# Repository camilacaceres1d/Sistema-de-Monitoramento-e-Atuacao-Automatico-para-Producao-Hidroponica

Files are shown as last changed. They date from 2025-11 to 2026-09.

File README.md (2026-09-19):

# Sistema de Monitoramento e Atuação Automático para Produção Hidropônica

Monitoramento e automação de cultivo hidropônico NFT com módulos ESP32, broker MQTT e aplicação web em Phoenix LiveView.

## Visão geral

Na técnica NFT, uma lâmina fina de solução nutritiva circula continuamente pelas raízes, e o cultivo depende de variáveis que mudam ao longo do dia: pH, condutividade elétrica, temperatura da solução, temperatura e umidade do ar, vazão e fotoperíodo. Em pequena escala, o acompanhamento é feito por medições manuais esporádicas, com bomba e iluminação em timer e sem registro histórico.

Este sistema mede essas variáveis a cada 15 segundos, grava a série histórica em banco, exibe as leituras em tempo real na web e aciona bomba e lâmpada por cronogramas configuráveis.

Custo aproximado: R$ 195,06 por módulo de reservatório e R$ 98,57 por bancada, cerca de R$ 293 para um sistema com um reservatório e uma bancada.

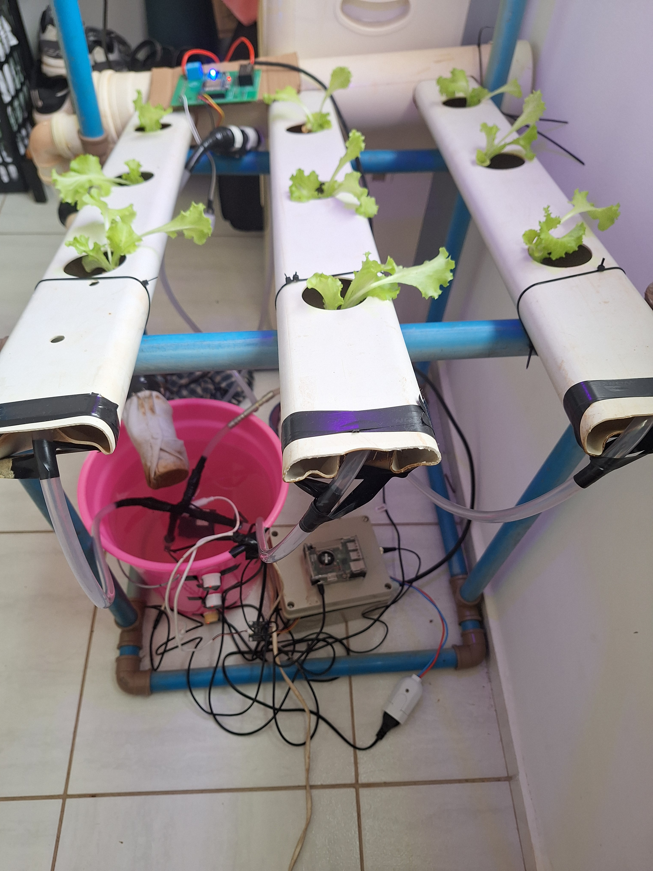
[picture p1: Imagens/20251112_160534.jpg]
Estufa hidropônica montada: três canais NFT, reservatório com as sondas de pH, EC, temperatura e nível, e o módulo de bancada fixado na estrutura


_Protótipo em operação: canais NFT em PVC, reservatório com a bomba e as sondas, módulo ESP32 da bancada no alto e caixa de passagem com o relé._

## Arquitetura

Três níveis, ligados por MQTT:

```mermaid
flowchart TB
    subgraph controle["Controle geral"]
        broker["Broker MQTT<br/>Eclipse Mosquitto (MQTT v5)<br/>Docker · Raspberry Pi 3B+"]
        subgraph app["Aplicação web (nó BEAM único)"]
            mqtt["MqttClient<br/>GenServer :emqtt"]
            logica["Sensors · Devices · Greenhouse<br/>Oban: IrrigationWorker, LightWorker"]
            lv["LiveViews<br/>Dashboard e Device"]
            db[("PostgreSQL")]
            mqtt <--> logica
            logica <--> db
            logica <--> lv
        end
        broker <--> mqtt
    end

    subgraph estufa["Estufa hidropônica"]
        subgraph res["Controle do reservatório"]
            esp1["ESP32"]
            s1["pH · TDS/EC · DS18B20<br/>3x nível XKC-Y25-V"]
            a1["Bomba submersa 600 L/h<br/>via relé"]
            s1 --> esp1 --> a1
        end
        subgraph banc["Controle da bancada"]
            esp2["ESP32"]
            s2["DHT22 · fluxo YF-S201"]
            a2["Lâmpada LED E27<br/>espectro completo via relé"]
            s2 --> esp2 --> a2
        end
    end

    esp1 -- "greenhouse/&lt;mac&gt;/sensors" --> broker
    broker -- "greenhouse/&lt;mac&gt;/commands" --> esp1
    esp2 -- "bench/&lt;mac&gt;/sensors" --> broker
    broker -- "bench/&lt;mac&gt;/commands" --> esp2
```

O broker é o único ponto de encontro entre firmware e servidor: os ESP32 não conhecem o endereço da aplicação nem ela o deles, ambos falam com `hidroponia.local:1883`.

Cliente MQTT, regras de negócio, jobs agendados e processos LiveView rodam no mesmo nó BEAM. Uma leitura que chega pelo `MqttClient` é gravada pelo contexto `Sensors` e propagada por `Phoenix.PubSub` direto para os LiveViews conectados, sem API REST intermediária.

Um detalhe do esquema de tópicos: bancadas não carregam o identificador da estufa. A vinculação entre bancada e estufa fica no banco (`devices.greenhouse_id`, editável pela interface), então mover um módulo de bancada para outra estufa não exige recompilar firmware.

## Hardware

**Módulo do reservatório** (diagrama: `Imagens/DiagramaReservatorioAnotado.png`)

| Componente | Função |
| --- | --- |
| ESP32 (MH-ET Live MiniKit) | Leitura dos sensores, publicação MQTT, acionamento do relé |
| Sensor de pH PH-4502C | pH da solução nutritiva |
| TDS Meter V1.0 | Condutividade elétrica da solução, em µS/cm |
| DS18B20 | Temperatura da solução, usada na compensação de pH e EC |
| 3x XKC-Y25-V | Nível capacitivo sem contato, sem furar o reservatório |
| Módulo relé | Chaveamento da bomba |
| Bomba submersa 600 L/h | Circulação da solução pelos canais NFT |
| Fonte Hi-Link 5 V | Alimentação a partir da rede |

Total do módulo: **R$ 195,06**

**Módulo da bancada** (diagrama: `Imagens/DiagramaBancadaAnotado.png`)

| Componente | Função |
| --- | --- |
| ESP32 (MH-ET Live MiniKit) | Leitura dos sensores, publicação MQTT, acionamento do relé |
| DHT22 | Temperatura e umidade do ar |
| YF-S201 | Vazão na bancada, por contagem de pulsos em interrupção |
| Módulo relé | Chaveamento da lâmpada |
| Lâmpada LED E27 de espectro completo | Iluminação suplementar |
| Fonte Hi-Link 5 V | Alimentação a partir da rede |

Total do módulo: **R$ 98,57**

Pinos e constantes de calibração ficam no `include/config.hpp` de cada firmware. Esquemas em Fritzing: `DiagramaBancada.fzz` e `Imagens/DiagramaReservatorio.fzz`.

## Stack

**Firmware:** C++ sobre o framework Arduino, compilado com PlatformIO para a board `mhetesp32minikit`, com PubSubClient, ArduinoJson, DallasTemperature (reservatório) e DHT sensor library (bancada).

**Aplicação:** Elixir 1.15 com Phoenix 1.8, LiveView 1.1 e Bandit; PostgreSQL via Ecto, cronogramas no Oban, gráficos em ECharts, estilo em Tailwind e `emqtt` 1.14.4 como cliente MQTT (v5).

**Infraestrutura:** Eclipse Mosquitto e PostgreSQL 15 em Docker Compose, num Raspberry Pi 3B+. O broker escuta MQTT na 1883 e WebSockets na 9001.

## Estrutura do repositório

```
.
├── SistemaReservatorio/   firmware do reservatório: src/, include/, platformio.ini, Makefile
├── SistemaBancada/        firmware da bancada, mesma organização
├── sistema_controle/      aplicação Phoenix: lib/, assets/, priv/, mosquitto/, docker-compose.yml
└── Imagens/               diagramas, esquemas Fritzing e fotos do protótipo
```

## Como executar

### Pré-requisitos

- Elixir 1.15+ e Erlang/OTP compatível
- Docker e Docker Compose
- PlatformIO Core (`pio`) para os firmwares
- Um host acessível como `hidroponia.local` na rede local, onde roda o broker

### Broker MQTT e banco

Os dois sobem pelo Compose em `sistema_controle/`:

```bash
cd sistema_controle
docker compose up -d
```

O `mosquitto.conf` usa `allow_anonymous false` e exige `/mosquitto/config/password.txt`, que não é versionado. Crie o arquivo com o usuário do firmware e do servidor:

```bash
docker compose exec mosquitto mosquitto_passwd -c /mosquitto/config/password.txt hidroponia
docker compose restart mosquitto
```

O PostgreSQL sobe com banco `hidroponia_db`, usuário `hidroponia_user` e senha `123456`, iguais aos de `config/dev.exs`. Para trocar, defina `POSTGRES_DB`, `POSTGRES_USER` e `POSTGRES_PASSWORD` antes do `up` e ajuste o `dev.exs`.

### Aplicação web

```bash
cd sistema_controle
mix setup        # deps.get, ecto.create, ecto.migrate, seeds, assets.setup, assets.build
mix phx.server   # ou: iex -S mix phx.server
```

A interface fica em http://localhost:4000. Em desenvolvimento o endpoint escuta só em `127.0.0.1`; para acessar de outra máquina, troque `ip: {127, 0, 0, 1}` por `ip: {0, 0, 0, 0}` em `config/dev.exs`. O alias `mix precommit` compila com `--warnings-as-errors`, formata e roda os testes.

### Firmwares

Cada módulo é um projeto PlatformIO independente. Ajuste `include/config.hpp` com SSID, senha do Wi-Fi e credenciais do broker; os valores versionados são os do ambiente de testes. O endereço do broker também está em `sistema_controle/lib/sistema_controle/mqtt_client.ex` e precisa bater nos três arquivos.

```bash
cd SistemaReservatorio        # ou SistemaBancada
make upload ENV=mhetesp32minikit
make monitor                  # serial a 115200 baud
```

Em PlatformIO puro:

```bash
pio run -t upload --environment mhetesp32minikit
pio device monitor -b 115200
```

`make erase ENV=mhetesp32minikit` apaga a flash; `make compiledb ENV=mhetesp32minikit` regenera o `compile_commands.json` do clangd.

A calibração do pH usa a reta de `PH_CALIBRATION_A` e `PH_CALIBRATION_B`, em `config.hpp`. A função `calibrate_ph()` imprime ADC e tensão médios para levantar os dois pontos com soluções tampão.

## Protocolo MQTT

O identificador no tópico é o MAC retornado por `WiFi.macAddress()`, no formato `AA:BB:CC:DD:EE:FF`.

| Tópico | Sentido | Conteúdo |
| --- | --- | --- |
| `greenhouse/<mac>/sensors`  | ESP32 → servidor | Leituras do reservatório, a cada 15 s |
| `greenhouse/<mac>/commands` | Servidor → ESP32 | Acionamento da bomba |
| `bench/<mac>/sensors` | ESP32 → servidor | Leituras da bancada, a cada 15 s |
| `bench/<mac>/commands` | Servidor → ESP32 | Acionamento da lâmpada |

O servidor assina `greenhouse/+/sensors` e `bench/+/sensors` com QoS 0; cada firmware assina só o próprio tópico de comandos.

Leitura do reservatório, publicada em `greenhouse/AA:BB:CC:DD:EE:FF/sensors`:

```json
{
  "ph": 6.12,
  "ec": 1184.37,
  "temp": 23.68,
  "levels": { "level0": true, "level1": true, "level2": false },
  "pump": true,
  "ts": 1358230
}
```

`ec` é a condutividade em µS/cm. O firmware aplica a curva do TDS Meter (`133.42·V³ − 255.86·V² + 857.39·V`) sobre a tensão já compensada em temperatura, sem multiplicar pelo fator TDS de 0,5, então o valor publicado é condutividade e não sólidos dissolvidos em ppm. Os três níveis são booleanos de presença de água em alturas diferentes do reservatório. `ts` é o `millis()` da placa, não um horário absoluto: o registro temporal é o `inserted_at` gravado pelo servidor.

Leitura da bancada, publicada em `bench/AA:BB:CC:DD:EE:FF/sensors`:

```json
{
  "flow": 1.87,
  "air_temp": 26.4,
  "air_humidity": 62.1,
  "light": false,
  "ts": 1358430
}
```

Comandos, publicados pelo servidor:

```json
{ "atuador": "bomba", "valor": true }
```

```json
{ "atuador": "luz", "valor": true }
```

O firmware do reservatório só reage a `"atuador": "bomba"`, e o da bancada só a `"atuador": "luz"`. Outros valores são registrados no serial e ignorados.

Cadastro automático: ao receber mensagem de um MAC desconhecido, `Devices.create_or_update_device/2` cria o registro, nomeia como "Estufa N" ou "Bancada N" e, para estufas, cria a configuração padrão. Ligar um módulo novo na rede basta para ele aparecer na interface.

## Resultados

O sistema foi validado em um cultivo real de alface crespa.

| 05/11/2025 | 12/11/2025 |
| --- | --- |
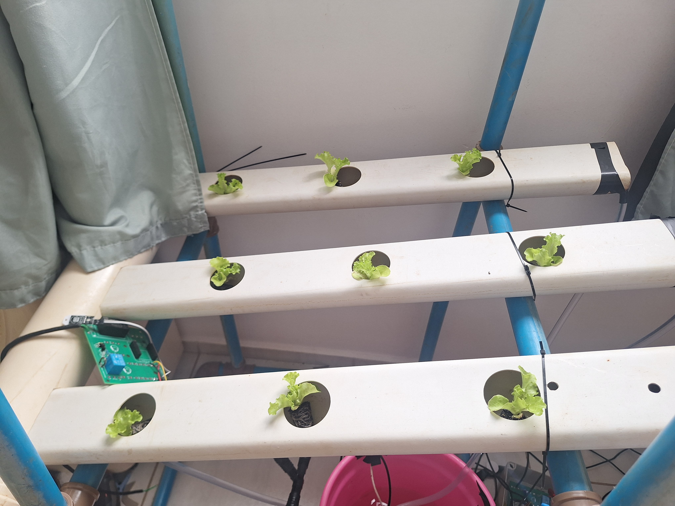
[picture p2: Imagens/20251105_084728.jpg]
Mudas de alface recém-transplantadas nos canais NFT
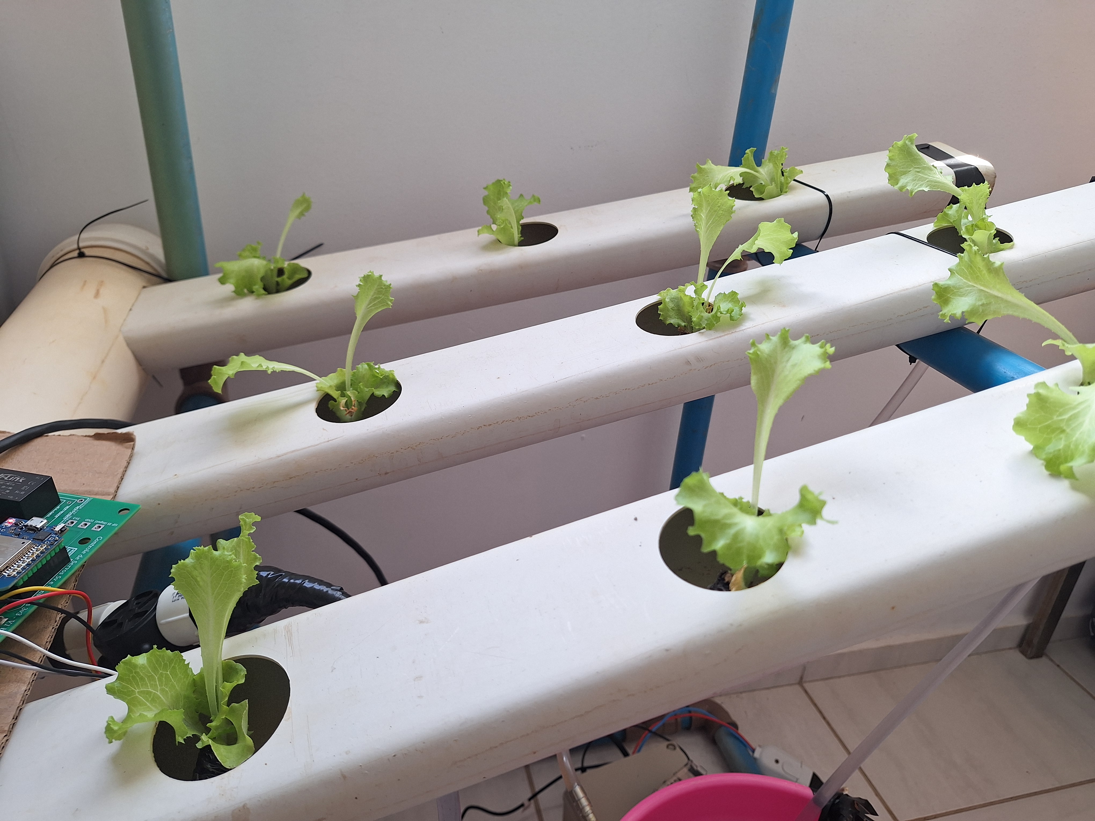
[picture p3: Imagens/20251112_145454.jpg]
Alfaces desenvolvidas nos mesmos canais uma semana depois
|  |  |
| Mudas recém-transplantadas, no início do monitoramento | As mesmas posições após uma semana de operação contínua |

Durante o ciclo, foram verificados:

- Telemetria dos dois módulos a cada 15 segundos, com série histórica persistida e visualização em tempo real
- Cadastro automático de módulos na primeira publicação
- Troca de uma bancada entre estufas pela interface, sem regravar firmware
- Cronogramas de bomba e lâmpada por janela de horário, dias da semana e ciclos liga/desliga em minutos
- Acionamento manual pela interface, com retorno do estado na leitura seguinte

**Limitação conhecida do sensor de pH.** O sensor de pH e o sensor de EC compartilham a mesma solução e o mesmo referencial de terra, e a excitação do eletrodo de EC injeta corrente na água que desloca a leitura do eletrodo de pH. A mitigação adotada é digital: `read_ph()` coleta 50 amostras, ordena o vetor e faz a média apenas do quartil central, descartando os extremos; a mesma filtragem é aplicada ao EC com 30 amostras, e ambas as leituras recebem compensação de temperatura a partir do DS18B20. A filtragem reduz o ruído, mas não elimina o desvio: a interferência eletroquímica permanece e a leitura de pH deve ser tratada como indicativa, com conferência periódica por medição manual. A solução definitiva passa por isolamento galvânico entre as sondas ou por alternar a excitação dos dois sensores no tempo.

## Publicação

Trabalho de conclusão de curso em Ciência da Computação, Faculdade de Computação (FACOM) da Universidade Federal de Mato Grosso do Sul (UFMS), 2025. Publicado nos anais do VII Congresso Brasileiro Interdisciplinar em Ciência e Tecnologia (COBICET), 2026.

> CÁCERES, Camila Cardoso; JUNQUEIRA, Luiz Gustavo S. S. **Sistema automático de monitoramento e atuação para produção hidropônica**. In: CONGRESSO BRASILEIRO INTERDISCIPLINAR EM CIÊNCIA E TECNOLOGIA, 7., 2026. Anais [...]. Even3, 2026.

https://www.even3.com.br/anais/cobicet2026-628540/1606975-sistema-automatico-de-monitoramento-e-atuacao-para--producao-hidroponica

## Autores

- Camila Cardoso Cáceres
- Luiz Gustavo S. S. Junqueira

Orientação: Profa. Hana Karina Salles Rubinsztejn (FACOM/UFMS).

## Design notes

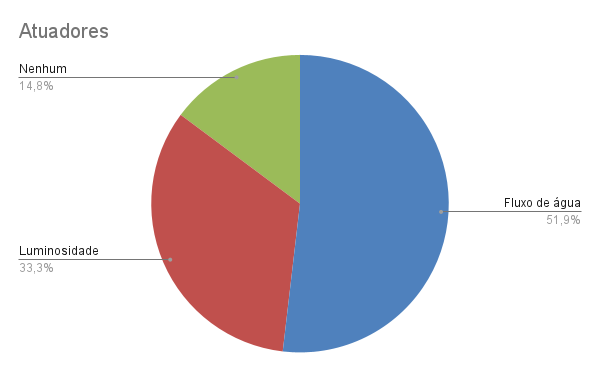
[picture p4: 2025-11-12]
Imagens/Atuadores.png

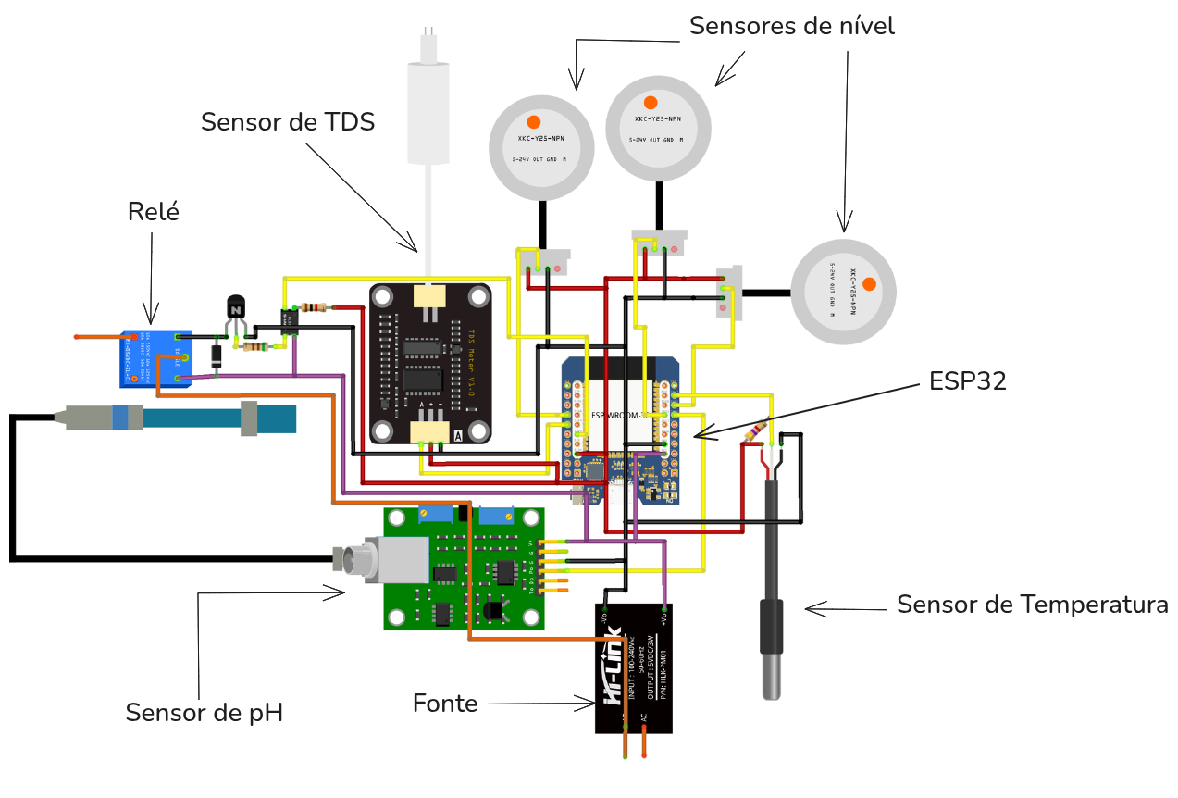
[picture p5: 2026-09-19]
Imagens/DiagramaReservatorioAnotado.png

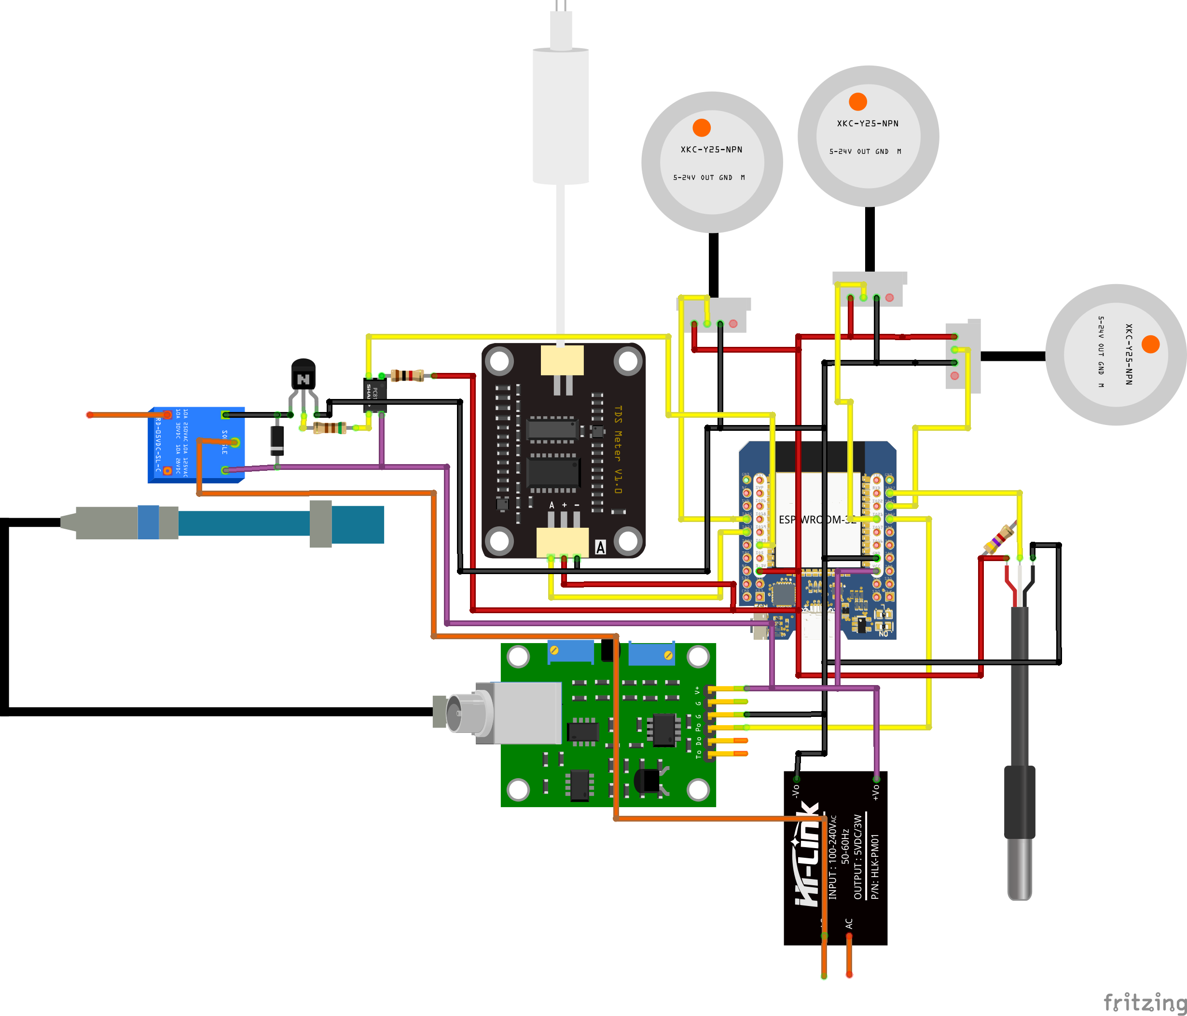
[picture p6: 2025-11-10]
Imagens/DiagramaReservatorio.png

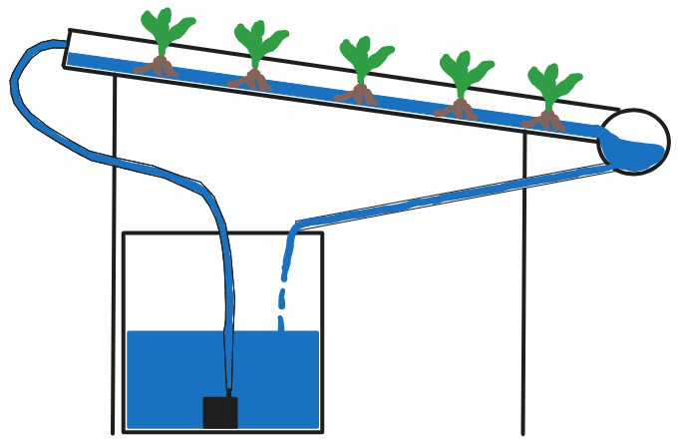
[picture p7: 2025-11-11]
Imagens/DiagramaNFT.png

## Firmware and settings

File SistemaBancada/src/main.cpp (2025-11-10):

#include <config.hpp>
#include <mqtt_comm.hpp>
#include <sensors_actuators.hpp>

double flow = 0;

void setup() {
  Serial.begin(115200);

  sensors_init();

  network_mqtt_setup();
  delay(500);
}

void loop() {
  network_mqtt_loop();

  static unsigned long lastRead = 0;

  read_water_flow(flow);
  if (millis() - lastRead >= 15000) {

    float airTemp, airHumidity;

    read_air_quality(airTemp, airHumidity);

    Serial.print("Water Flow: ");
    Serial.print(flow);
    Serial.print(" L/min, Air Temp: ");
    Serial.print(airTemp);
    Serial.print(" °C, Air Humidity: ");
    Serial.print(airHumidity);
    Serial.println(" %");
    mqtt_publish_sensors(flow, airTemp, airHumidity, get_light_state());

    lastRead = millis();
  }
}

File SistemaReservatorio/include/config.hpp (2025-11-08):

#pragma once
#include <Arduino.h>

#define WIFI_SSID "NET_2G4B4C9B"
#define WIFI_PASSWORD "4F4B4C9B"
#define MQTT_HOST "hidroponia.local"
#define MQTT_PORT 1883
#define MQTT_USER "hidroponia"
#define MQTT_PASSWORD "Hidroponia@123"

#define PUMP_PIN 23

#define PH_CALIBRATION_A -4.31005
#define PH_CALIBRATION_B 17.77498
#define PH_SENSOR_PIN 32
#define TDS_SENSOR_PIN 33
#define LEVEL0_SENSOR_PIN 21
#define LEVEL1_SENSOR_PIN 25
#define LEVEL2_SENSOR_PIN 35
#define TEMP_SENSOR_PIN 22
#define VREF 3.3
#define EC_MEASURE_COUNT 30
#define PH_MEASURE_COUNT 50

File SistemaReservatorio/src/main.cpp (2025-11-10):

#include <config.hpp>
#include <mqtt_comm.hpp>
#include <sensors_actuators.hpp>

void setup() {
  Serial.begin(115200);

  analogReadResolution(12);
  sensors_init();

  network_mqtt_setup();
  delay(500);
}

void loop() {
  network_mqtt_loop();

  static unsigned long lastRead = 0;
  if (millis() - lastRead >= 15000) {

    float tempNow = read_temperature_c();
    float ec = read_ec(TDS_SENSOR_PIN, tempNow);
    float ph =
        read_ph(PH_SENSOR_PIN, PH_CALIBRATION_A, PH_CALIBRATION_B, tempNow);

    bool level0 = read_water_presence(LEVEL0_SENSOR_PIN);
    bool level1 = read_water_presence(LEVEL1_SENSOR_PIN);
    bool level2 = read_water_presence(LEVEL2_SENSOR_PIN);

    Serial.print("pH: ");
    Serial.print(ph);
    Serial.print(" | EC: ");
    Serial.print(ec);
    Serial.print(" | Temp: ");
    Serial.print(tempNow);
    Serial.print(" | Level0: ");
    Serial.print(level0);
    Serial.print(" | Level1: ");
    Serial.print(level1);
    Serial.print(" | Level2: ");
    Serial.print(level2);
    Serial.print(" | Pump: ");
    Serial.println(get_pump_state() ? "ON" : "OFF");
    mqtt_publish_sensors(ph, ec, tempNow, level0, level1, level2,
                         get_pump_state());
    lastRead = millis();
  }
}

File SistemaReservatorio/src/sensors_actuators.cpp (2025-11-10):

#include <sensors_actuators.hpp>

static bool pumpOn = false;

static OneWire oneWire(TEMP_SENSOR_PIN);
static DallasTemperature tempSensor(&oneWire);
static float lastValidTempC = NAN;

void sensors_init() {
  tempSensor.begin();

  pinMode(PH_SENSOR_PIN, INPUT);
  pinMode(TDS_SENSOR_PIN, INPUT);
  pinMode(LEVEL0_SENSOR_PIN, INPUT);
  pinMode(LEVEL1_SENSOR_PIN, INPUT);
  pinMode(LEVEL2_SENSOR_PIN, INPUT);
  pinMode(PUMP_PIN, OUTPUT);
  digitalWrite(PUMP_PIN, HIGH); // HIGH é OFF e LOW é ON
}

int ph_buffer[PH_MEASURE_COUNT];
float read_ph(uint8_t pin, float a, float b, float temperature) {

  for (int i = 0; i < PH_MEASURE_COUNT; i++) {
    ph_buffer[i] = analogRead(pin);
    delay(10);
  }

  for (int i = 0; i < PH_MEASURE_COUNT - 1; i++) {
    for (int j = i + 1; j < PH_MEASURE_COUNT; j++) {
      if (ph_buffer[i] > ph_buffer[j]) {
        int temp = ph_buffer[i];
        ph_buffer[i] = ph_buffer[j];
        ph_buffer[j] = temp;
      }
    }
  }

  int start = PH_MEASURE_COUNT / 4;
  int end = (PH_MEASURE_COUNT * 3) / 4;
  int countUsed = end - start;
  long sum = 0;
  if (countUsed > 0) {
    for (int i = start; i < end; ++i)
      sum += ph_buffer[i];
  } else {
    countUsed = PH_MEASURE_COUNT;
    for (int i = 0; i < PH_MEASURE_COUNT; ++i)
      sum += ph_buffer[i];
  }

  float avgAdc = (float)sum / (float)countUsed;
  float m = (avgAdc * VREF) / 4095.0f;
  Serial.print("pH - tensão média: ");
  Serial.println(m, 2);

  float ph = a * m + b; // reta do pH

  if (isnan(temperature)) {
    temperature = 25.0f;
  }
  return ph + (25.0 - temperature) * 0.03;
}

int ec_buffer[EC_MEASURE_COUNT];
float read_ec(uint8_t pin, float temperature) {

  for (int i = 0; i < EC_MEASURE_COUNT; i++) {
    ec_buffer[i] = analogRead(pin);
    delay(5);
  }

  for (int j = 0; j < EC_MEASURE_COUNT - 1; j++) {
    for (int i = 0; i < EC_MEASURE_COUNT - j - 1; i++) {
      if (ec_buffer[i] > ec_buffer[i + 1]) {
        int tmp = ec_buffer[i];
        ec_buffer[i] = ec_buffer[i + 1];
        ec_buffer[i + 1] = tmp;
      }
    }
  }

  int start = EC_MEASURE_COUNT / 4;
  int end = (EC_MEASURE_COUNT * 3) / 4;
  int countUsed = end - start;
  long sum = 0;
  if (countUsed > 0) {
    for (int i = start; i < end; ++i)
      sum += ec_buffer[i];
  } else {
    countUsed = EC_MEASURE_COUNT;
    for (int i = 0; i < EC_MEASURE_COUNT; ++i)
      sum += ec_buffer[i];
  }

  float avgAdc = (float)sum / (float)countUsed;
  float voltage = avgAdc * (VREF / 4095.0f);

  if (isnan(temperature)) {
    temperature = 25.0f;
  }
  float coeff = 1.0 + 0.02 * (temperature - 25.0);
  float compVoltage = voltage / coeff;

  return (133.42 * compVoltage * compVoltage * compVoltage -
          255.86 * compVoltage * compVoltage + 857.39 * compVoltage);
}

bool read_water_presence(uint8_t pin) { return digitalRead(pin) == HIGH; }

float read_temperature_c() {
  tempSensor.requestTemperatures();
  delay(50);
  float t = tempSensor.getTempCByIndex(0);
  if (t == DEVICE_DISCONNECTED_C) {
    Serial.println("Erro: Sensor de temperatura desconectado!");
    return lastValidTempC;
  }
  lastValidTempC = t;
  return t;
}

void set_pump(bool on) {
  pumpOn = on;
  Serial.print("Set pump: ");
  Serial.println(on ? "ON" : "OFF");
  digitalWrite(PUMP_PIN, on ? LOW : HIGH);
}

bool get_pump_state() { return pumpOn; }

void calibrate_ph(uint8_t pin) {
  const int samples = 10;
  int readings[samples];

  for (int i = 0; i < samples; i++) {
    readings[i] = analogRead(pin);
    delay(30);
  }

  for (int i = 0; i < samples - 1; i++) {
    for (int j = i + 1; j < samples; j++) {
      if (readings[i] > readings[j]) {
        int tmp = readings[i];
        readings[i] = readings[j];
        readings[j] = tmp;
      }
    }
  }

  long sum = 0;
  for (int i = 2; i < samples - 2; i++)
    sum += readings[i];

  float avgAdc = (float)sum / (samples - 4);
  float voltage = (avgAdc * VREF) / 4095.0f;

  Serial.print("ADC médio: ");
  Serial.println(avgAdc, 2);
  Serial.print("Tensão média: ");
  Serial.print(voltage, 4);
  Serial.println(" V");
}

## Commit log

2025-09-29 feat: add ph sensor calibration code
2025-09-30 feat: ec sensor reading
2025-10-27 feat: finish sensor testing
2025-10-27 docs: system diagrams
    [DiagramaHardware1.fzz]
2025-11-04 feat: finish actuator testing
2025-11-04 feat: refactor sensor code
2025-11-05 feat: add project structure for sistema de controle geral
2025-11-05 feat(control): sensor data table
2025-11-05 feat(control): create device table
2025-11-06 feat(control): pump button and better styles
2025-11-08 feat: Sistema de monitoramento da bancada
2025-11-08 fix: ajuste de captura do endereço mac
    [mqtt_comm.cpp]
2025-11-08 fix: ph calibration with comercial sensor
    [config.hpp, main.cpp, sensors_actuators.cpp]
2025-11-09 fix(control): validações de irrigação
2025-11-10 docs: update hardware diagrams
    [DiagramaBancada.fzz, DiagramaHardware1.fzz, DiagramaReservatorio.fzz]
2025-11-12 fix: general fixes
    [DiagramaReservatorio.fzz]
